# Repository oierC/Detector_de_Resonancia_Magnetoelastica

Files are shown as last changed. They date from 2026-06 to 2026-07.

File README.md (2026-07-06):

# Detector de Resonancia Magnetoelástica – Archivos del TFG

Este repositorio recopila los principales archivos desarrollados durante mi Trabajo Fin de Grado del Grado en Ingeniería Electrónica sobre el diseño y construcción de un dispositivo Detector de Resonancia Magnetoelástica.

<p align="center">
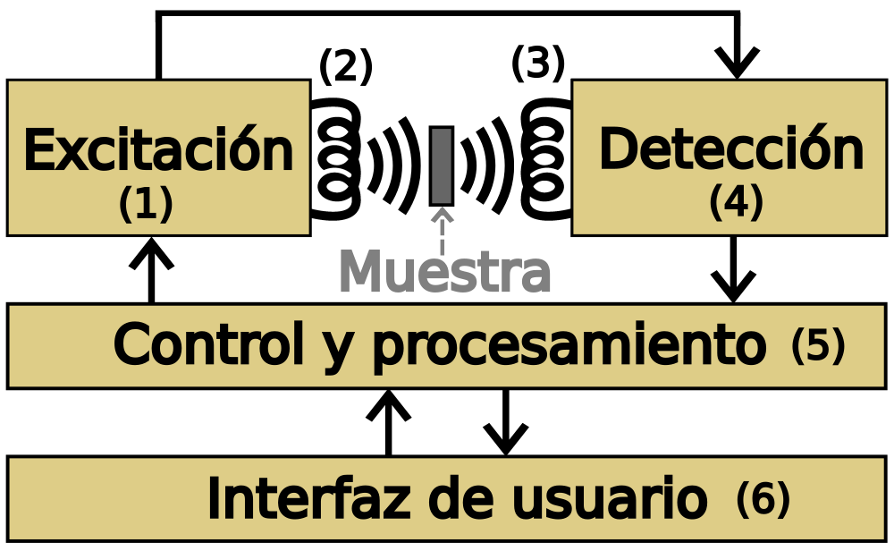
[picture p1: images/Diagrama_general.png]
  
</p>

El contenido se organiza en los siguientes tipos de archivos:

* **Arduino:** firmware principal del detector, desarrollado para ESP32. Se encarga del control de todos los elementos hardware del sistema, incluyendo el generador de señal, los convertidores DAC, el potenciómetro digital y la adquisición de datos mediante el ADC. Implementa distintos modos de funcionamiento (control manual, acceso a parámetros de calibración y barridos automáticos), gestionando la generación de campos magnéticos continuos y alternos, la ejecución de barridos en frecuencia y campo magnético, la adquisición de las señales de ganancia y fase, así como la comunicación con el software de control mediante el puerto serie. Además, incorpora comprobaciones de rango y resolución, junto con indicadores luminosos y acústicos para informar del estado del sistema y de posibles errores.

<p align="center">
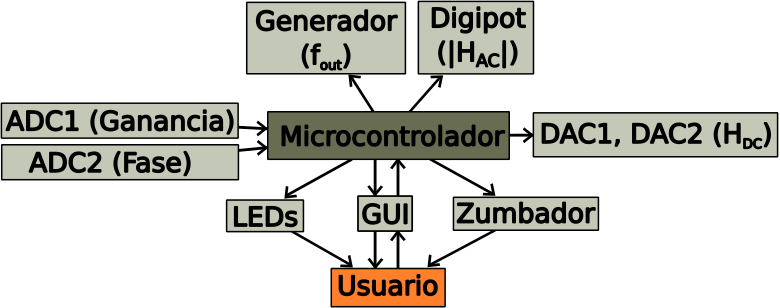
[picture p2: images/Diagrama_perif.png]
  
</p>

* **Python:** aplicación de escritorio desarrollada para el control del detector y la visualización de resultados. Proporciona una interfaz gráfica (GUI) desde la que es posible configurar los parámetros de medida, establecer barridos de frecuencia del campo magnético alterno y de valor del campo magnético estático, consultar los parámetros de calibración del sistema y comunicarse con el microcontrolador a través del puerto serie. Durante la adquisición de datos recibe en tiempo real las medidas de amplitud y fase, representa gráficamente su evolución, muestra la frecuencia de resonancia para cada valor de campo magnético estático y permite exportar los resultados obtenidos en formato CSV para su posterior análisis. Además, incorpora detección automática de dispositivos compatibles, gestión de errores y notificaciones del estado del sistema.

<p align="center">
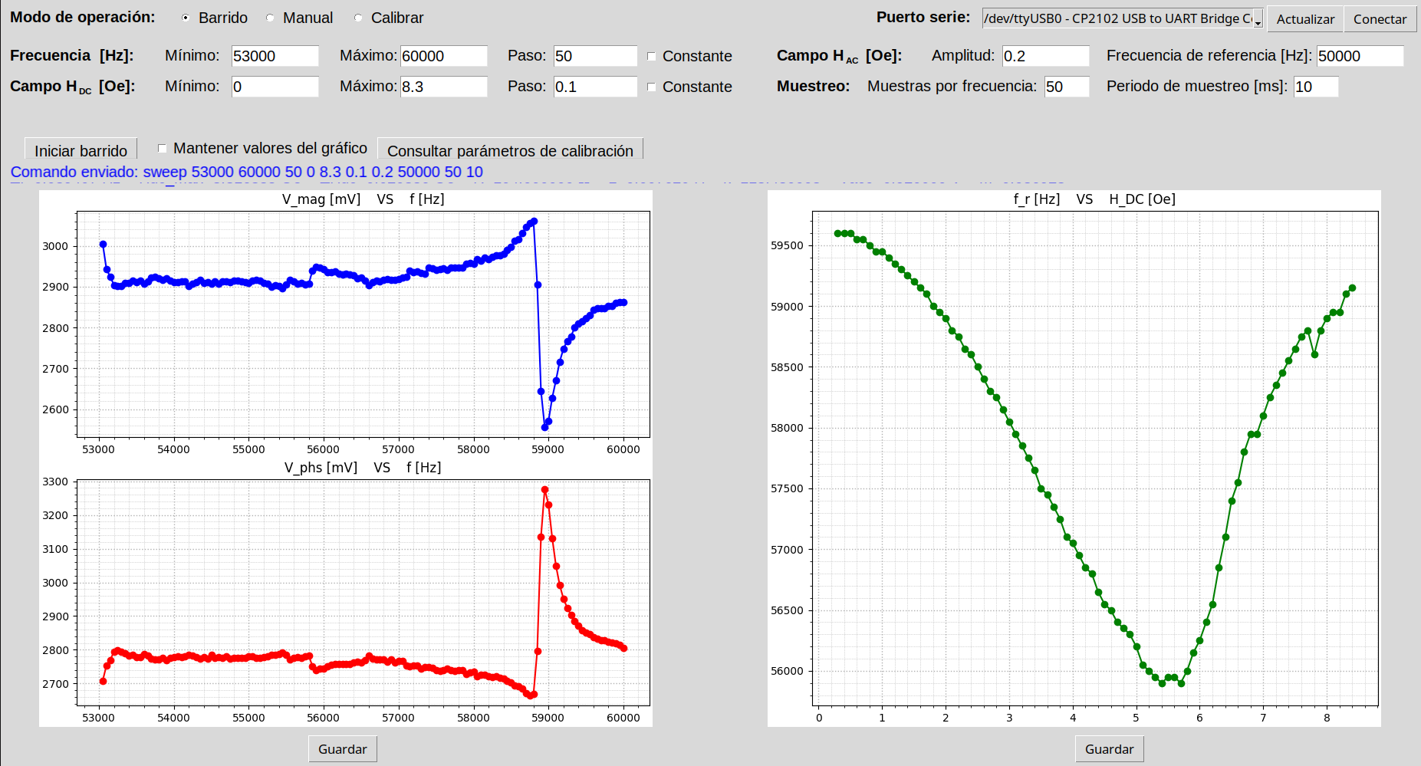
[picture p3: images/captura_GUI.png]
  
</p>

* **Modelos 3D:** diseños CAD de las piezas de PETG fabricadas para el sistema magnético encargado de generar y medir el campo magnético. Incluye dos soportes para fijar dos solenoides de forma coaxial. Estos soportes integran orificios para la introducción de muestras en el interior del sistema, cavidades para para el acoplamiento de conectores coaxiales y orificios roscantes que permiten fijar los solenoides mediante tornillos. Además, también incluye una tapa para cubrir la soldadura de los conectores y un portamuestras con referencias milimétricas que permiten posicionar las muestras en el interior del sistema.
  
<p align="center">
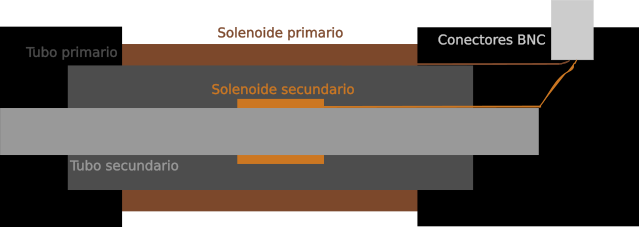
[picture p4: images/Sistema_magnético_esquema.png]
  
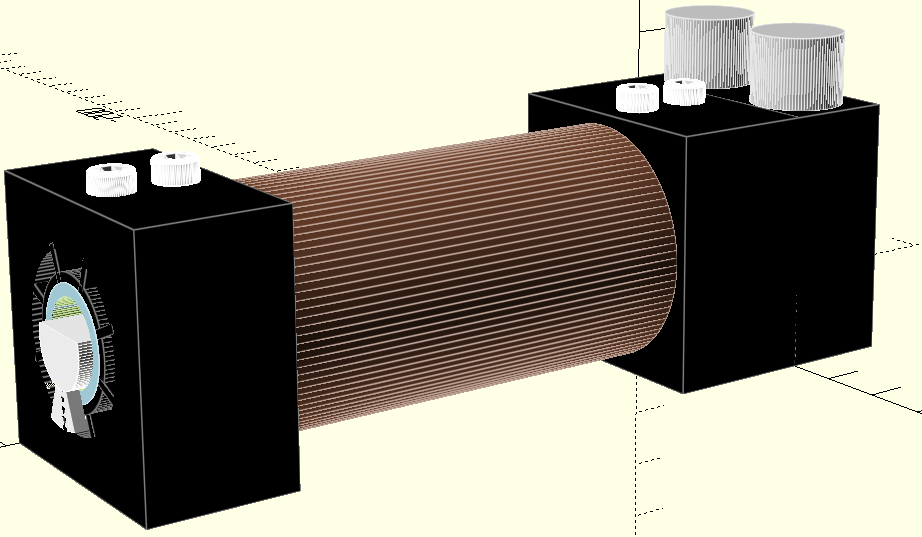
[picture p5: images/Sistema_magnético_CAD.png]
  
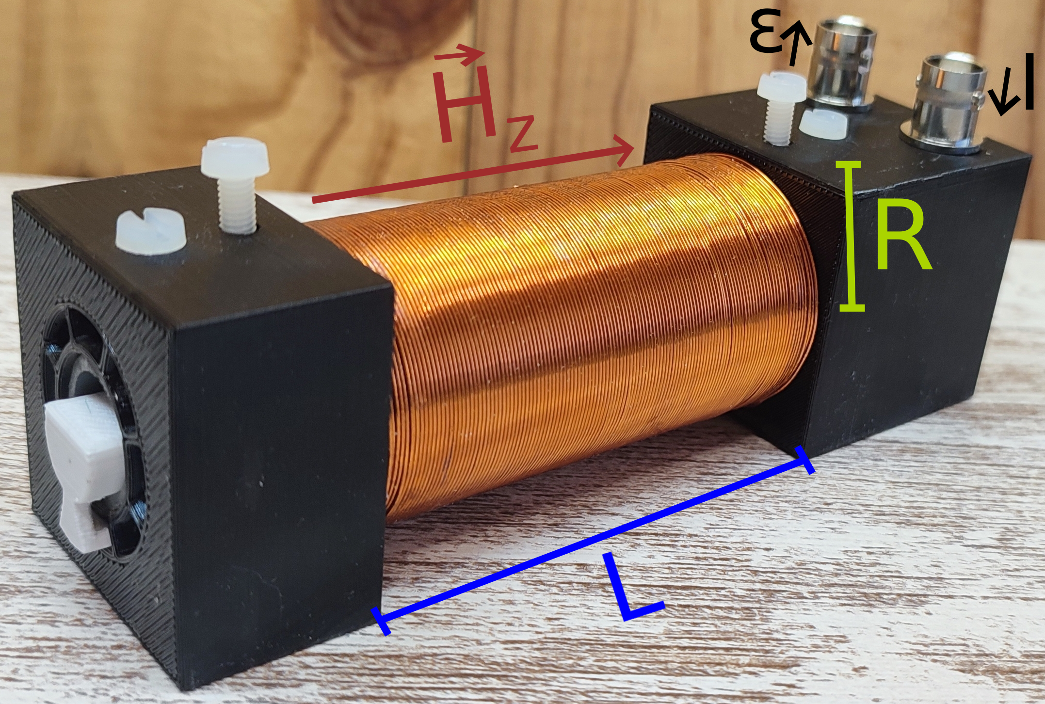
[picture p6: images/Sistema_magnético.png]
  
</p>
  
* **KiCad:** esquema eléctrico y diseño de la placa de circuito impreso (PCB) del prototipo preindustrializado desarrollado para el proyecto. Incluye el generador de señal, circuito de adecuación y amplificación, el detector de ganancia y fase, el sistema de control y procesamiento, un conector USB tipo-C para la comunicación y conectores coaxiales para el sistema magnético.
  
<p align="center">
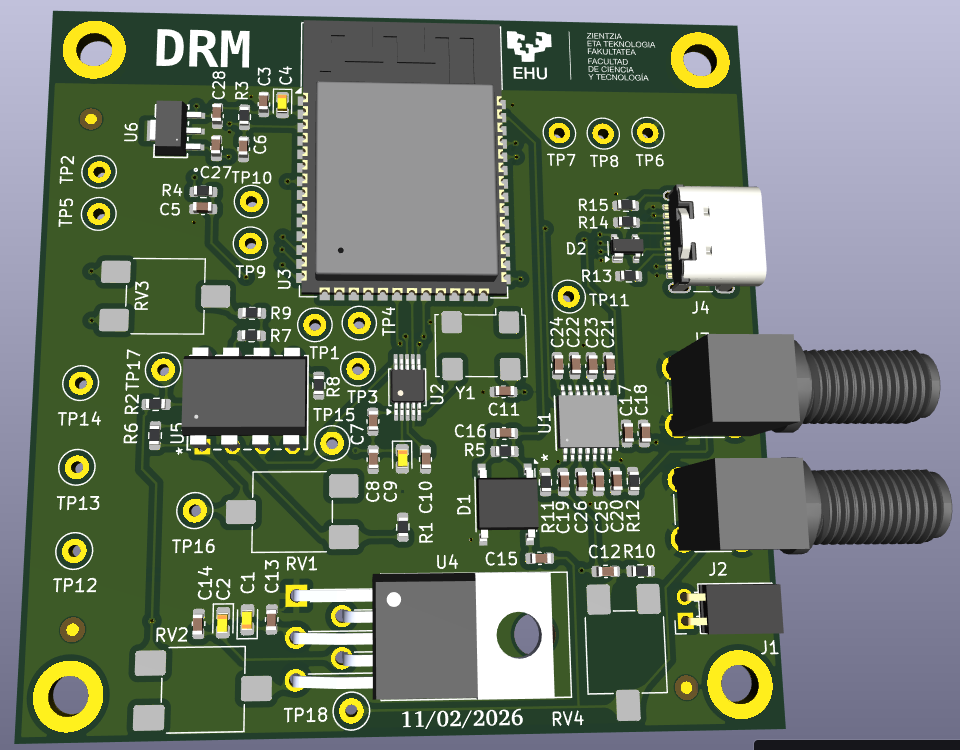
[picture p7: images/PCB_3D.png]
  

Este repositorio tiene como objetivo facilitar la consulta, reproducción y reutilización del trabajo realizado, reuniendo en un único lugar tanto el hardware como el software desarrollados para el proyecto.

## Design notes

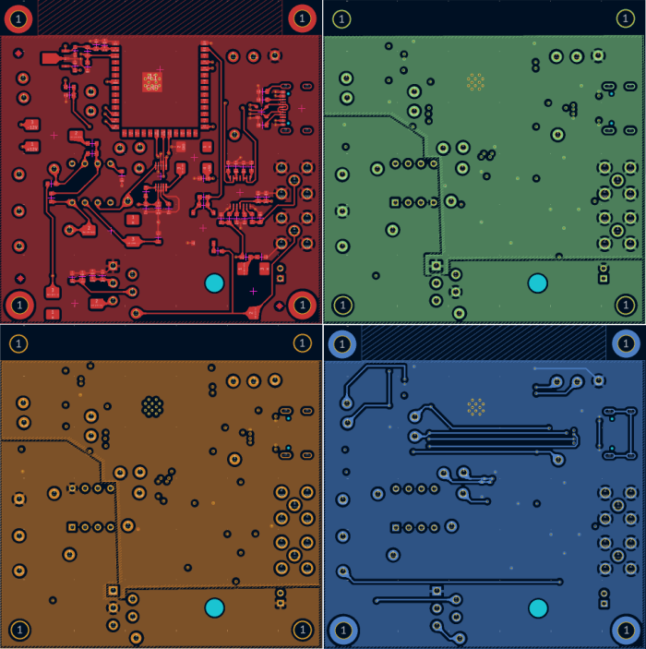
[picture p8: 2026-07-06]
images/PCB_capas.png

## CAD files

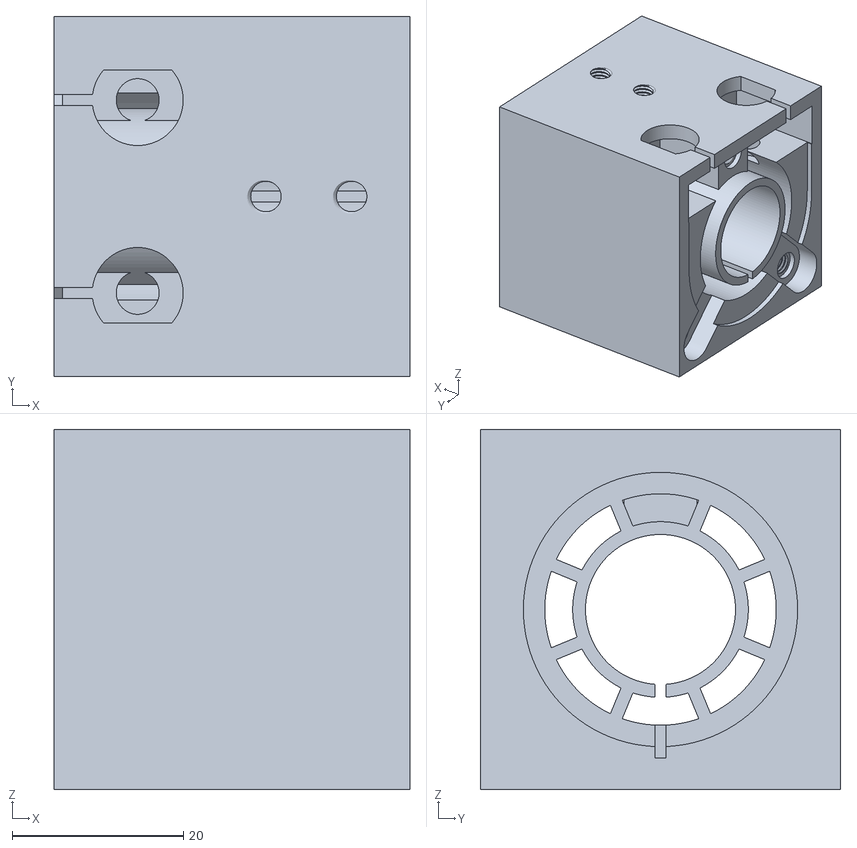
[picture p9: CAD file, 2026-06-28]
Modelos_3D/baseRight_V5.stl
41.5 x 42.0 x 42.0

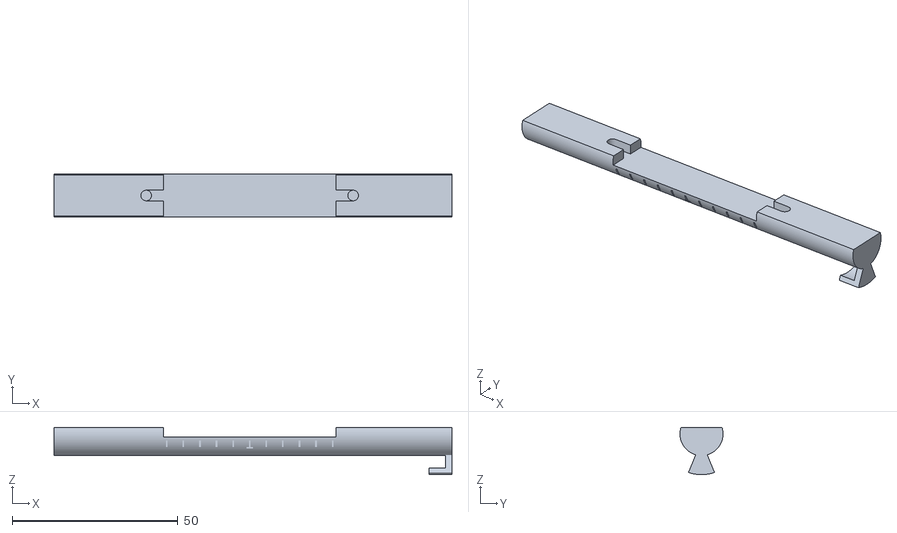
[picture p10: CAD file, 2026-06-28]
Modelos_3D/portamuestras_V7.stl
120.0 x 13.0 x 14.2

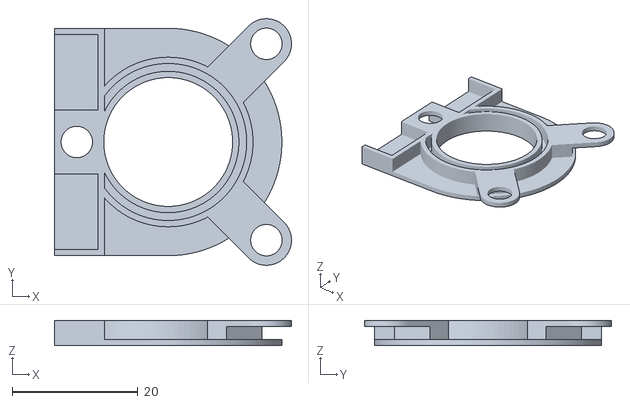
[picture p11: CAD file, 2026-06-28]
Modelos_3D/tapa_V5.stl
37.7 x 39.3 x 4.00

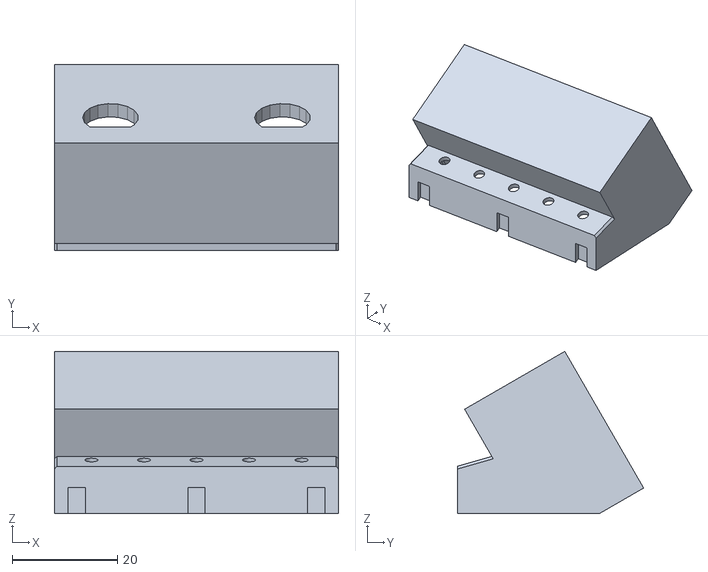
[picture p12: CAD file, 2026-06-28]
Modelos_3D/extension_SMA.stl
54.0 x 35.4 x 30.8

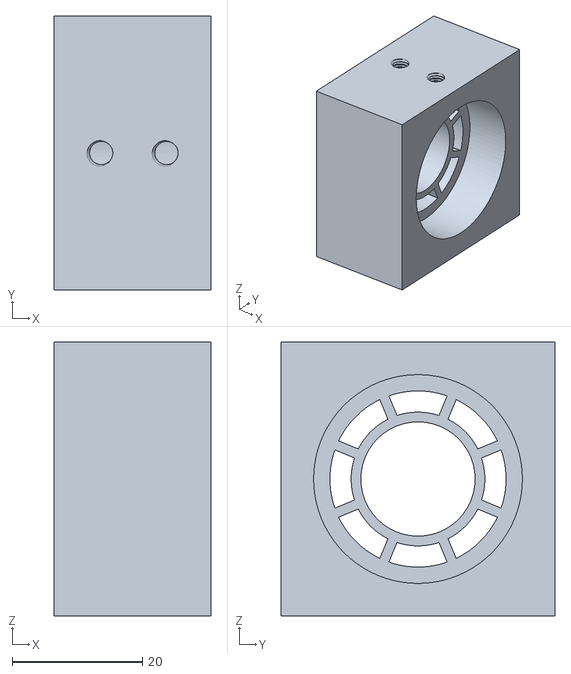
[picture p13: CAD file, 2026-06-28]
Modelos_3D/baseLeft_V5.stl
24.0 x 42.0 x 42.0

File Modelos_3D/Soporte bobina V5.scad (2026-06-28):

// Soporte bobina TFG Oier
//
dtp = 32; // diametro externo tubo primario
ltp = 90; // largo tubo primario
//ltp = 100; // largo tubo primario
dts = 17.5; // diametro externo tubo secundario;
gts = 2; // Grosor tubo secundario
thick = 24; // ancho de la pieza soporte
sobra = 5; // cuanto es mayor la pieza soporte del diametro del tubo
monta = 10; // longitud que monta en el soporte el tubo primario
anillo = 5; // anillo exterior de radios
lts = ltp+2*(thick-monta); // largo tubo secundario
sobra_sec = 3; // pared del soporte del secundario.
da =1.3; // diamtero agujero pasa hilos
desfase = 22.5;

//Parametros de tornillos:
dtorn = 5; //Diametro rosca tornillo. Nota: Este no es el diametro real de la rosca, es un agujero de un diametro más grande pensado para luego unirle por dentro un modelo 3D de tuerca de 4mm.
dcab = 8;  //Diametro cabeza tornillo. El diametro real es de 7, pero le damos un pequeño margen
lcab = 3; //Altura cabeza tornillo
ltorn1 = 5.3; //Largo tornillo1. Nota: Le hemos añadido un margen de 0.5mm.
ltorn2 = 12.7; //Largo tornillo2. Nota: Le hemos añadido un margen de 0.2mm.
ltuerca4mm = 3; //Altura de la tuerca de 4mm

//Parametros del conector SMA:
dr = 10.6; //diametro rosca del conector SMA
drmin = 8.8; //diametro de la zona con muesca muesca de la rosca del conector SMA
muesca= dr-drmin; //tamaño de la mordida
lr = 8; //largo rosca

dSMA = 15.5; //Diametro máximo del macho SMA
lSMA = 12; //Largo de la parte metálica del conector que queda en el exterior
dTuerca = 12.5;
lTuerca = 2.3;

dpunt = 5; //Diametro punta de cobre de SMA
lpunt = 7; //Largo punta de cobre de SMA

//Parametros de la extensión:
margenx = 10; //Margen de espacio entre el conector y la pared de la base
margeny = 2; //Margen de espacio entre el conector y los bordes de la extensión
margenz = 2; //Margen de altura entre el suelo y el SMA
//paredy = 2.9; //Grosor de las paredes en ele eje y
//paredx = 2.9; //Grosor de las paredes en ele eje x
pared = 2.9; //Grosor de las paredes. El fabricante del conector SMA indica explicitamente que la pared en la que se sujeta puede tener un groso máximo de 2.9mm
largo = margenx+lr; //Como de larga es la extensión
alto = dSMA+margenz; //Cómo de alta es la extensión

//Tapa cubre conexiones:
sobraTapa = 5; //Sobrante entre final de hueco y final de tapa
gruesoTapa = 1; //Grosor de la tapa
lDientes= lcab; //Como de largo serán los salientes que sujetan la tapa
dtapa = anillo+sobraTapa; //Diametro máximo de la parte cricular de la tapa
wBase=dtp+2*sobra-2*pared; //Anchura de la zona rectangular
hBase=dtp/2+sobra-pared; //Altura de la zona rectangular
dBase=wBase;    //dtp-anillo+sobraTapa; //Diametro de la zona circular.
lPalo=dBase+dcab;
wPalo=dcab;

//Portamuestras
lmmax = 50; //Longitud máxima de las muestras. Suelen ser de unos 30-50mm.
wmmax = 11; //Anchura máxima de las muestras. Suelen ser de unos 5mm.
hmmax = 1.65; //Altura máxima de las muestras. De momento no lo sé, supongamos 1mm.
lm = lmmax+2;
wm = wmmax+2;
hm = hmmax+0.2;
gsuelo = 2; //Grosor del suelo del portamuestras sobre el que se posaran las muestras.
hparedes=hm+2;
sport = 2; //Sobrante axial del portamuestras.
lsuj = 5;//Longitud del saliente de sujección
rsport = 2*gts+2*sobra_sec+1; //Sobrante radial del portamuestras.
gpatas = lsuj+5; //Grosor de las patas del portamuestras.
hpatas = dts/2-gts-gsuelo-hmmax/2; //altura de las patas.
//Largo tapaNeg = ltorn1+lcab+1 = 5.1 + 3 + 1= 10.1mm
//Largo extension = alto = dSMA+margenz = 15.5 + 2 = 17.7
$fn=100;

module m4nut(){
    import("/home/oier/Desktop/Code/3D/STL/working-m4-screws-and-nut-model_files/m4-nut.stl");
}

module tornillo_m4_5mm(){
    import("/home/oier/Desktop/Code/3D/STL/working-m4-screws-and-nut-model_files/m4-5mm-screw.stl");
}
module tornillo_m4_12mm(){
    import("/home/oier/Desktop/Code/3D/STL/working-m4-screws-and-nut-model_files/m4-12mm-screw.stl");
}


module soporte_primario() {
    translate([thick-monta, dtp/2+sobra, dtp/2+sobra]) rotate([0,90,0]) cylinder(h=ltp,d=dtp);
}

module soporte_secundario() {
    difference(){
        
        translate([0, dtp/2+sobra, dtp/2+sobra])
        rotate([0,90,0])
        cylinder(h=lts,d=dts);
        
        translate([-0.1, dtp/2+sobra, dtp/2+sobra])
        rotate([0,90,0])
        cylinder(h=lts+0.2,d=dts-2*gts);
    }
}

module radio(angle) {
    radio_thick = 1.5;
    translate([(thick-monta)/2,dtp/2+sobra, dtp/2+sobra]) 
    rotate([angle,0,0]) 
    cube([thick-monta,radio_thick,dtp-anillo+2], center = true);
}

module radioPorta(angle,radio_thick) {
    //radio_thick = 1.5;
    //translate([(thick-monta)/2,dtp/2+sobra, dtp/2+sobra]) 
    rotate([angle,0,0]) 
    cube([lsuj+sport+0.2,radio_thick,dtp-anillo+2], center = true);
}

module soporte() {
    
    difference() {
        union() {
            difference() {
              cube([thick,dtp+2*sobra,dtp+2*sobra]);
                soporte_primario();
                translate([0, dtp/2+sobra, dtp/2+sobra])
                rotate([0,90,0])
                cylinder(h=ltp,d=dtp-anillo, center=true);   
            }
            radio(0+desfase);
            radio(45+desfase);
            radio(90+desfase);
            radio(90+45+desfase);
            translate([0, dtp/2+sobra, dtp/2+sobra])
            rotate([0,90,0])
            cylinder(h=thick-monta,d=dts+sobra_sec);
        }
        translate([-1,0,0])
        soporte_secundario();
    }
}

module tornillo1(){
    translate([0,0,0])
    cylinder(h=ltorn1,d = dtorn);

    translate([0,0,ltorn1])
    cylinder(h=3,d = dcab);
}

module tornillo1V7mm(){
    translate([0,0,0])
    cylinder(h=ltorn1,d = dtorn);

    translate([0,0,ltorn1])
    cylinder(h=3,d = 7);
}

module tornillo2(){
    translate([0,0,0])
    cylinder(h=ltorn2,d = dtorn);

    translate([0,0,ltorn2])
    cylinder(h=3,d = dcab);
}

module pasacablesV1(){
    translate([-0.5*thick,dtp/2+sobra,sobra-0.25*da]) rotate([0,90,0]) cylinder(h=2*thick,d = da);
    translate([-0.5*thick,dtp/2+sobra,da]) rotate([0,90,0]) cylinder(h=2*thick,d = da);
    translate([-0.5*thick,dtp/2+sobra,dtp/2+sobra-dts/2]) rotate([0,90,0]) cylinder(h=2*thick,d = da);
    }
    
module pasacablesV2(){
    radio_thick = da;
    h= (dtp-dts)/2+da+1;
    h_pos=sobra-da;
    translate([-3,dtp/2+sobra-radio_thick/2,h_pos])
    cube([thick+6,radio_thick,h], center = false);
    }
    
module SMA(){
    union(){
        //Rosca:
        difference(){
            translate([0, 0, lpunt])
            rotate([0,0,0])
            cylinder(h=lr,d=dr);
            
            translate([-dr,dr/2-muesca,-1])
            cube([20,20,20], center = false);
        }
        //Exterior:
        translate([0,0,lr+lpunt])
        cylinder(h=lSMA,d=dSMA);
        
        //Tuerca:
        translate([0,0,lr+lpunt-pared-lTuerca])
        cylinder(h=lTuerca,d=dTuerca);
        
        //Punta:
        translate([0, 0, 0])
        rotate([0,0,0])
        cylinder(h=lpunt,d=dpunt);
        
    }
}

module SMA2(){
    //Este va ha ser para asegurar espacio de cavidad
    union(){
        //Rosca:
        difference(){
            translate([0, 0, lpunt])
            rotate([0,0,0])
            cylinder(h=lr,d=dr);
            
            translate([-dr,dr/2-muesca,-1])
            cube([20,20,20], center = false);
        }
        //Exterior:
        translate([0,0,lr+lpunt])
        cylinder(h=lSMA,d=dSMA);
        
        //Tuerca:
        translate([0,0,lr+lpunt-pared-lTuerca])
        cylinder(h=lTuerca,d=dTuerca);
        
        //Punta:
        translate([0, 0, 0])
        rotate([0,0,0])
        cylinder(h=lpunt,d=dpunt);
        
        //Cavidad:
        esp1_alto = 3*dr/4;
        esp1_ancho = dTuerca+1.5;
        translate([0,0,lpunt+lr-esp1_alto/2-pared])
        cube([esp1_ancho+10,esp1_ancho,esp1_alto], center=true);
        
    }
}

module dualSMA(){
//    margenx = 10; //Margen de espacio entre el conector y la pared de la base
//    margeny = 2; //Margen de espacio entre el conector y los bordes de la extensión
//    margenz = 2; //Margen de altura entre el suelo y el SMA
//    pared = 3; //Grosor de las paredes
    union(){
        rotate([180,90,0])
        translate([-(dSMA/2+margenz),-dSMA/2-margeny,margenx-lr])
        SMA();
        
        rotate([0,-90,0])
        translate([dSMA/2+margenz,dtp+2*sobra-dSMA/2-margeny,margenx-lr])
        SMA();
    }
}
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

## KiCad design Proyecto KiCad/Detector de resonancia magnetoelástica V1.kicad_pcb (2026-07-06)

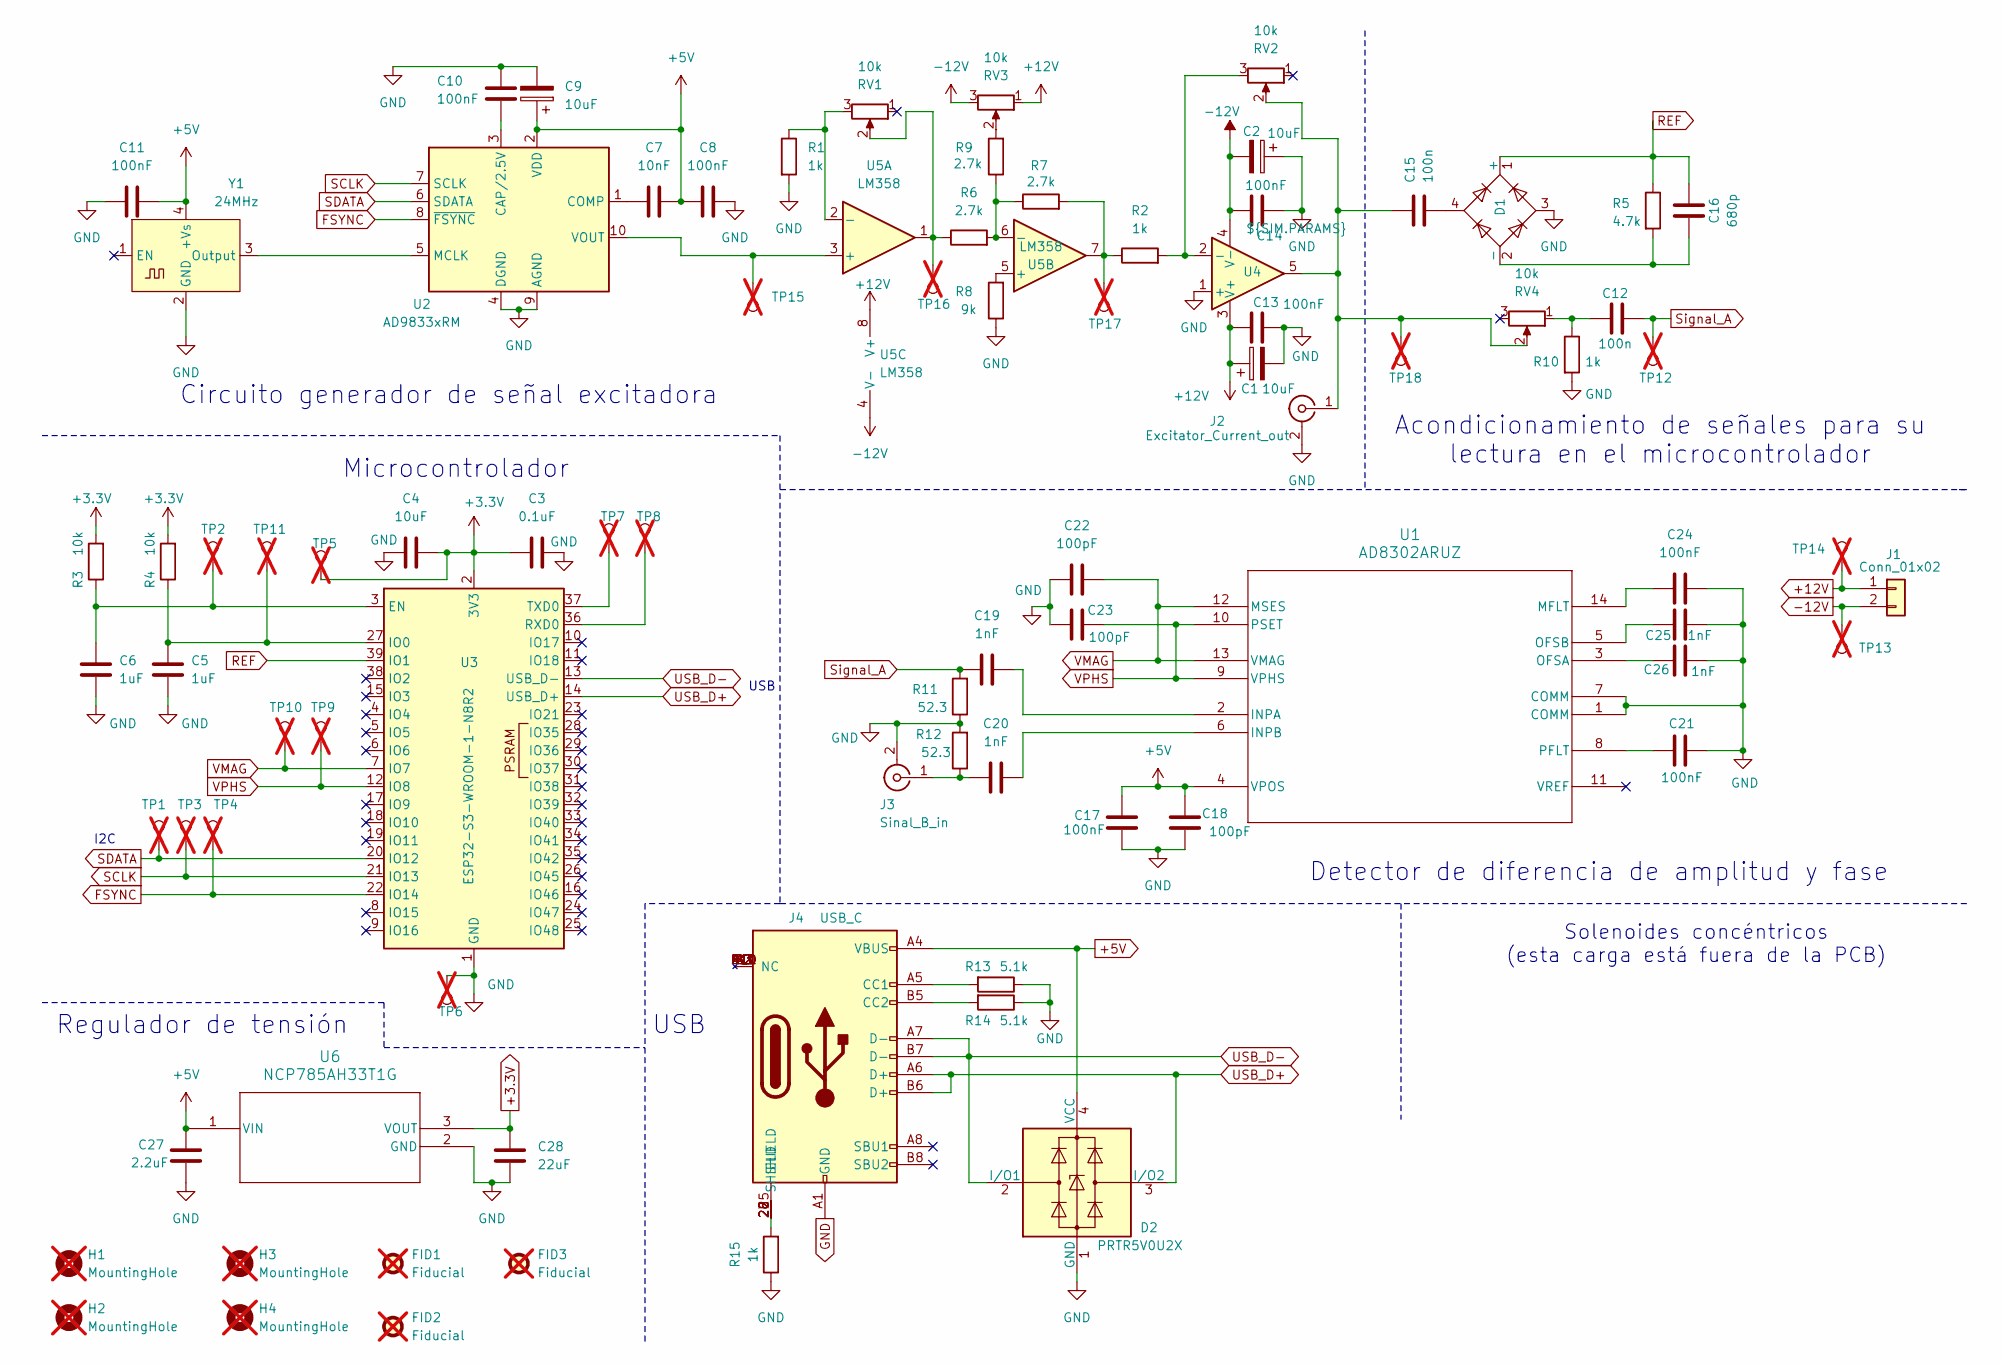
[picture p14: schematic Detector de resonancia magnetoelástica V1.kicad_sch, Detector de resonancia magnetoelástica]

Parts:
C1, C2, C4, C9: 10uF; CP_EIA-1608-08_AVX-J
C3: 0.1uF; C_0603_1608Metric
C5, C6: 1uF; C_0603_1608Metric
C7: 10nF; C_0603_1608Metric
C8, C10, C11, C13, C14, C17, C21, C24: 100nF; C_0603_1608Metric
C12, C15: 100n; C_0603_1608Metric
C16: 680p; C_0603_1608Metric
C18, C22, C23: 100pF; C_0603_1608Metric
C19, C20, C25, C26: 1nF; C_0603_1608Metric
C27: 2.2uF; C_0603_1608Metric
C28: 22uF; C_0603_1608Metric
D1: ABS2; Diode_Bridge_Diotec_ABS
D2: PRTR5V0U2X; SOT-143
FID1, FID2, FID3: Fiducial; Fiducial_1mm_Mask2mm; not fitted
H1, H2, H3, H4: MountingHole; MountingHole_3.2mm_M3_DIN965_Pad_TopBottom; not fitted
J1: Conn_01x02; PinSocket_1x02_P2.00mm_Horizontal
J2: Excitator_Current_out; SMA_Molex_73251-2200_Horizontal
J3: Sinal_B_in; SMA_Molex_73251-2200_Horizontal
J4: USB_C; USB_C_Receptacle_GCT_USB4105-xx-A_16P_TopMnt_Horizontal
R1, R2, R10, R15: 1k; R_0603_1608Metric
R3, R4: 10k; R_0603_1608Metric
R5: 4.7k; R_0603_1608Metric
R6, R7, R9: 2.7k; R_0603_1608Metric
R8: 9k; R_0603_1608Metric
R11, R12: 52.3; R_0603_1608Metric
R13, R14: 5.1k; R_0603_1608Metric
RV1, RV2, RV3, RV4: 10k; Potentiometer_ACP_CA6-VSMD_Vertical
TP1, TP2, TP3, TP4, TP5, TP6, TP7, TP8, TP9, TP10, TP11, TP12, TP13, TP14, TP15, TP16, TP17, TP18: TestPoint; TestPoint_Loop_D2.50mm_Drill1.0mm; not fitted
U1: AD8302ARUZ; RU_14_ADI-L
U2: AD9833xRM; MSOP-10_3x3mm_P0.5mm
U3: ESP32-S3-WROOM-1-N8R2; ESP32-S3-WROOM-1
U4: ${SIM.PARAMS}; TO-220-5_P3.4x3.8mm_StaggerOdd_Lead7.13mm_TabDown
U5: LM358; DIP8
U6: NCP785AH33T1G; SOT-89-3_2P7X4P7_ONS-M
Y1: 24MHz; Oscillator_SMD_IQD_IQXO70-4Pin_7.5x5.0mm

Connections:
+3.3V: C3.1, C4.2, C28.1, R3.2, R4.2, TP5.1, U3.2 (3V3), U6.3 (VOUT)
+5V: C7.2, C8.1, C9.1, C11.2, C17.1, C18.1, C27.1, D2.4 (VCC), J4.A4 (VBUS), J4.A9 (VBUS), J4.B4 (VBUS), J4.B9 (VBUS), U1.4 (VPOS), U2.2 (VDD), U6.1 (VIN), Y1.4 (+Vs)
+12V: C1.1, C13.2, J1.1, RV3.1, TP14.1, U4.3 (V+), U5.8 (V+)
-12V: C2.2, C14.2, J1.2, RV3.3, TP13.1, U4.4 (V-), U5.4 (V-)
FSYNC: TP4.1, U2.8 (~FSYNC), U3.22 (IO14)
GND: C1.2, C2.1, C3.2, C4.1, C5.2, C6.2, C8.2, C9.2, C10.2, C11.1, C13.1, C14.1, C17.2, C18.2, C21.2, C22.1, C23.1, C24.2, C25.2, C26.2, C27.2, C28.2, D1.3, D2.1 (GND), J2.2 (Ext), J3.2 (Ext), J4.A1 (GND), J4.A12 (GND), J4.B1 (GND), J4.B12 (GND), R1.2, R8.1, R10.2, R11.1, R12.2, R13.1, R14.1, R15.1, TP6.1, U1.1 (COMM), U1.7 (COMM), U2.4 (DGND), U2.9 (AGND), U3.1 (GND), U3.40 (GND), U3.41 (GND), U4.1 (+), U6.2 (GND), Y1.2 (GND)
unnamed: C12.1, R10.1, RV4.1
unnamed: C15.2, D1.4
unnamed: C16.1, D1.2 (-), R5.2
unnamed: C15.1, J2.1 (In), RV2.2, RV4.2, TP18.1, U4.5
unnamed: C20.1, J3.1 (In), R12.1
unnamed: J4.A5 (CC1), R13.2
unnamed: J4.B5 (CC2), R14.2
unnamed: J4.25 (SHIELD), J4.26 (SHIELD), J4.27 (SHIELD), J4.28 (SHIELD), J4.S1, R15.2
unnamed: R2.1, R7.2, TP17.1, U5.7
unnamed: R6.1, RV1.2, TP16.1, U5.1
unnamed: R9.2, RV3.2
unnamed: C19.2, U1.2 (INPA)
unnamed: C20.2, U1.6 (INPB)
unnamed: C24.1, U1.14 (MFLT)
unnamed: C26.1, U1.3 (OFSA)
unnamed: C25.1, U1.5 (OFSB)
unnamed: C21.1, U1.8 (PFLT)
unnamed: C10.1, U2.3 (CAP/2.5V)
unnamed: C7.1, U2.1 (COMP)
unnamed: U2.5 (MCLK), Y1.3 (Output)
unnamed: TP15.1, U2.10 (VOUT), U5.3 (+)
unnamed: C6.1, R3.1, TP2.1, U3.3 (EN)
unnamed: C5.1, R4.1, TP11.1, U3.27 (IO0)
unnamed: TP8.1, U3.36 (RXD0)
unnamed: TP7.1, U3.37 (TXD0)
unnamed: R2.2, RV2.3, U4.2 (-)
unnamed: R1.1, RV1.3, U5.2 (-)
unnamed: R8.2, U5.5 (+)
unnamed: R6.2, R7.1, R9.1, U5.6 (-)
REF: C16.2, D1.1 (+), R5.1, U3.39 (IO1)
SCLK: TP3.1, U2.7 (SCLK), U3.21 (IO13)
SDATA: TP1.1, U2.6 (SDATA), U3.20 (IO12)
Signal_A: C12.2, C19.1, R11.2, TP12.1
USB_D+: D2.3 (I/O2), J4.A6 (D+), J4.B6 (D+), U3.14 (USB_D+)
USB_D-: D2.2 (I/O1), J4.A7 (D-), J4.B7 (D-), U3.13 (USB_D-)
VMAG: C22.2, TP10.1, U1.12 (MSES), U1.13 (VMAG), U3.7 (IO7)
VPHS: C23.2, TP9.1, U1.9 (VPHS), U1.10 (PSET), U3.12 (IO8)

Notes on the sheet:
Detector de diferencia de amplitud y fase
Circuito generador de señal excitadora
USB
Regulador de tensión
Microcontrolador
I2C
Solenoides concéntricos (esta carga está fuera de la PCB)
USB
Acondicionamiento de señales para su lectura en el microcontrolador

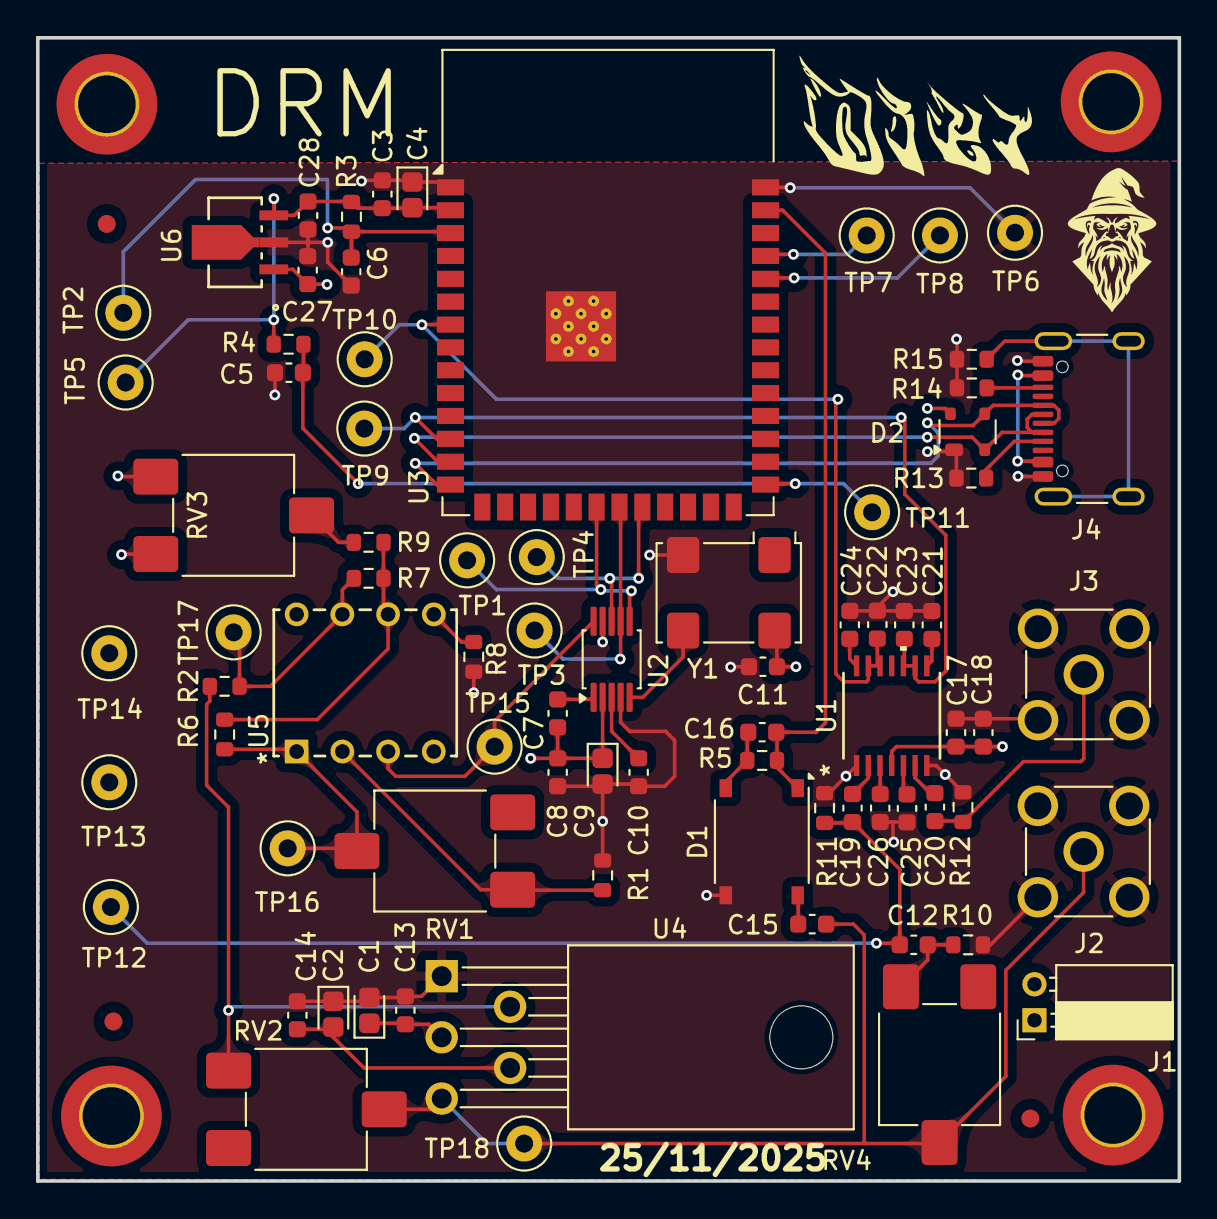
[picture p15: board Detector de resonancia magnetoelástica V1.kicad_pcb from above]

Board: 4 copper layers, 63.4 x 63.5 mm, 85 parts (0 on the bottom side), 43 nets.

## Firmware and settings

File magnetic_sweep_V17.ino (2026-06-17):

/// Título: magnetic_sweep_V10
/// Descripción:
/// * V7: Controla el generador de señales sinusoidales a través del puerto serie con dos sencillas funciones con instrucciones en binario.
/// * V8: Se implementa el multitasking para controlar los indicadores LED.
/// * V8: Se implementa la interfaz de indicadores LED y zumbador.
/// * V9: Se implementa el control de los DAC.
/// * V10: Ligera mejora del control del DAC y el generador para poder hacer barridos manteniendo frecuencia o Hdc constantes.
/// * V11: Se implementa el control del digipot.
/// * V11: Se implementa recogida de errores de resolución y rango de frecuencia, campo H continuo y campo H alterno.
/// * V12: Se implementa recolección de datos a través del ADC.
/// * V13: Se implementan melodías en lugar de pitidos.
/// * V14: Se han ajustado los periodos de cambio de frecuencia y muestreo.
/// * V14: Se ha hecho un ajuste en los bucles de f y Hdc, ya que no llegaban nunca a tomar medidas con los valores máximos.
/// * V15: Se implementa la recogida de más errores de resolución y rango de frecuencia y campo H continuo.
/// * V15: Las variables samples_per_f y sample_period son ahora parámetros de entrada.
/// * V16: El primer parámetro de entrada pasa a ser una cadena de caracteres que indica el comando. Entradas admitidas, cmd="sweep","params"
/// * V17: Añadido los comandos cmd="man" para control manual y cmd="raw" para control a través de los valores en crudo de registros.

// Los comandos de entrada del microcontrolador tendrán siempre los mismos 8 parámetros separados por espacios:
// char[10] cmd    float f_min    float f_max    float f_step    float Hdc_min    float Hdc_max    float Hdc_step    H0_1Hz
// Si cmd="sweep" --> se pone en marcha el sistema magnético con los parámetros indicados; Si cmd = "params" --> El microcontrolador devuelve los parámetros de calibración guardados en su memoria.


// Ejemplo de comando:
// 0 50000 65000 1000 0 2 1 0.15 50000

#include <SPI.h>

// Parámetros de calibración
// >>Nota: El usuario debe ajustar estos valores en función de los componentes empleados y la calibración realizada mediante potenciómetros.
const float f_MCLK = 24*pow(10,6); // Hz // Introducir frecuencia del oscilador externo del generador de señal AD9833.
const float R = 104; // Ohms // Introducir valor de resistencia de carga.
const float L = 0.00762; // Henrios // Introducir valor de inductancia del solenoide primario.
const float k = 118.48; // 1/m // Introducir constante de solenoide del solenoide primario.
const float Voffset = -0.046;//345; // Volts // Introducir tensión medida con el generador en modo reposo y los DACs apagados.
//const float Vdc1_max = 1.945; // Volts // Introducir tensión máxima medida con DAC1 (DAC2=0).
//const uint8_t DAC2_min = 255; // Introducir valor del DAC1 en escala de 8 bits al medir la tensión máxima.
const float Vdc2_min = -7.3; // Volts // Introducir tensión mínima medida con DAC2 (DAC1=0).
const uint8_t DAC2_min = 255; // Introducir valor del DAC2 en escala de 8 bits al medir la tensión mínima.
const float Vdc1_max = 0.055; // Volts // Introducir con que aporte míninimo de tensión de DAC1 se iguala o supera al Voffset o -kv2. Es decir, Vdc1 mínimo para que: Vdc1>=Voffset o Vdc1>=(-kv2). Este será el aporte máximo de Vdc1 que empleará este programa.
const uint8_t DAC1_max = 3; // Introducir valor del DAC1 en escala de 8 bits al medir la tensión anterior. Este será el valor de DAC máximo que empleará este programa.
const float Vac0 = 0.92; // Volts // Introducir amplitud de tensión medida en la salida cuando digipot=0;
const float Vac_max = 7.4; // Volts // Introducir amplitud de tensión máxima medida en la salida.
const uint8_t digipot_max = 180; // Introducir valor de entrada del digipot en escala de 8 bits al medir la tensión anterior.
const float Vac_punto = 2.6; // Volts // Introducir amplitud de tensión medida en la salida para un valor intermedio del digipot.
const uint8_t digipot_punto = 50; // Introducir valor de entrada del digipot en escala de 8 bits al medir la tensión anterior.

// Parámetros derivados de los parámetros de calibración introducidos.
// >> Nota: Los cálculos y funciones se han hecho suponiendo que DAC2 es coarse tuning (ya que depende únicamente de una de las resistencias variables) y que DAC1 es para fine tuning, por lo que Hdc estará en el rango negativo. A partir de ahora cada vez que se mencione Hdc se estará refiriendo a su módulo.
const float clock_constant = pow(2,28) / f_MCLK; // s // Constante de proporcionalidad que determina el valor requerido en el registro de frecuencia para lograr una determinada frecuencia de salida.
const float f_step_min = 1/clock_constant; // Hz // Resolución de frecuencia del generador de señal.
const float kv2 = (Vdc2_min+Voffset)/DAC2_min; // Volts // Salida de tensión continua dependiente de la salida del DAC2: Vdc2 = kv2*V_DAC2;
const float kv1 = Vdc1_max/DAC1_max; // Volts // Salida de tensión continua dependiente de la salida del DAC1: Vdc1 = kv1*V_DAC1;
// Hdc = k*(Vdc1+Vdc2)/R
const float Hdc_absolute_max = -k*Vdc2_min/R; // Oersteds // Valor máximo del campo magnético continuo que puede proporcionar el sistema.
const float Hdc_step_min = k*kv1/R; // Oersteds // Resolución del campo magnético.
const float m = (Vac_max-Vac_punto)/(digipot_max-50); // Pendiente de la ganancia de la amplitud en función del valor del digipot
// Hac = k*Gm*(Vac0+m*digipot_valor), donde Gm es la transconductancia de la carga de salida y digipot_valor es el valor de entrada del digipot en escala de 8 bits.


// SPI conexiones
#define csPin_wavegen 5   // AD9833 CS -> ESP32 GPIO5
#define csPin_digipot 15   // MCP4151 CS -> ESP32 GPIO5
#define sckPin 18  // SPI SCK -> ESP32 GPIO18
#define mosiPin 23  // SPI MOSI -> ESP32 GPIO23

// Indicadores LED
#define ledPin_V 21 // Verde
#define ledPin_A 19 // Azul
#define ledPin_R 17 // Rojo

// Zumbador
#define buzzerPin 16

// DACs
#define dacPin 25   //DAC1
#define dacPin2 26   //DAC2

// ADCs
#define gainPin 4 // Salida detector de ganancia
#define phasePin 2 // Salida detector de fase

// Configuraciones de SPI
SPISettings wavegenSettings(1000000, SPI_MSBFIRST, SPI_MODE2); //En el AD9833 es SPI_MSBFIRST.
SPISettings digipotSettings(1000000, SPI_MSBFIRST, SPI_MODE0);

// Variables globales
int modo = 0; // Modo = 0 --> Conexión por puerto serie (LED verde); Modo = 1 --> Conexión por WiFi (LED rojo); Modo = 2 --> Conexión por Bluetooth (LED azul)
// bool request = true; // request = true --> En reposo (solo se enciende en LED del modo correspondiente); request = false --> Campo magnético activo (barrido de los 3 LEDs en bucle). Al recibir por el puerto serie request=true, envía los parámetros de calibración.
float last_f = 0; // Hz // Para tener constancia a nivel global del valor actual de f y evitar redundancias.
float last_Hdc = 0; // Oersted // Para tener constancia a nivel global del valor actual de Hdc y optimizar procesos.
float last_Hac = 0; // Oersted // Para tener constancia a nivel global del valor actual de Hac y optimizar procesos.
float f_min = 0; // Hz
float f_max = 100000; // Hz
float f_step = 50; // Hz //Originalmente era 50
uint8_t DAC1_valor = 0; // Valor del registro del DAC1
uint8_t DAC2_valor = 0; // Valor del registro del DAC2
uint8_t digipot_valor = 0; // Valor del registro del digipot
float Hdc_min = 0; // Oersted
float Hdc_max = 0; // Oersted
float Hdc_step = 0; // Oersted
float Hac_at_f = 0; // Oersted // Valor del campo deseado a f_at_Hac Hz.
float f_at_Hac = 0; // Hz // Frecuencia a la que se desea la amplitud de campo Hac_at_f.
bool barrido = false; // Indica que hay un barrido en proceso
int samples_per_f = 30; // Cantidad de muestras por cada valor de frecuencia. // Valor recomedado para máxima velocidad: 30. Valor recomendado para mayor equilibrio velocidad/precisión: 50.
int sample_period = 10; // ns
char cmd[10];

// Melodias
struct Note {
    int freq;
    int duration;
};

#define C3  131
#define CS3 139
#define E3  165
#define F3  175
#define FS3 185
#define G3  196
#define GS3 208
#define A3  220
#define AS3 233
#define C4  262
#define CS4 277

Note deviceInitialization[] = {
    {C3, 120},
    {C4, 120},
    {G3, 120},
    {E3, 120},
    {C4, 100},
    {G3, 140},
    {E3, 240},

    {E3, 60},
    {F3, 60},
    {FS3, 60},
    {FS3, 60},
    {G3, 60},
    {GS3, 60},
    {GS3, 60},
    {A3, 60},
    {AS3, 60},
    {C4, 180},
};

Note connected[] = {
    {523, 80},
    {659, 80},
    {784, 80},
    {1047, 150}
};

Note commandError[] = {
    {440, 200},
    {330, 300}
};

Note sweepStart[] = {
    {1200, 40},
    {1350, 40},
    {1500, 40},
    {1800, 80},
    {1600, 50}
};

Note sweepEnd[] = {
    {900, 120},
    {1100, 120},
    {900, 120},
    {1100, 200}
};

// Se define una tarea que será ejecutada en un núcleo diferente al del programa principal, con el fin de ejecutar la animación de luces LED en paralelo al programa principal.
TaskHandle_t Task1;

void initializeWavegen(){
  SPI.beginTransaction(wavegenSettings);
  digitalWrite(csPin_wavegen, LOW);
  SPI.transfer16(0b0010000100000000);//(0b0010000100000000); ///Preparar reg. control, RESET, B28
  SPI.transfer16(0b0100000000000000); // FREQREG LSB
  SPI.transfer16(0b0100000000000000); // FREQREG MSB
  SPI.transfer16(0b1100000000000000); // Reg. fase=0
  SPI.transfer16(0b0010000001000000);//(0b0010000000000000); // Cargar reg. interno, modo reposo
  digitalWrite(csPin_wavegen, HIGH);
  SPI.endTransaction();
  last_f = 0;
}

void setWavegenFrecuency(float f_out){
  if (f_out < 0) f_out = -f_out; // Para corregir la entrada de posibles frecuencias negativas.
  if (f_out != last_f){
    uint32_t FREQREG = f_out * clock_constant; // Valor que debe tener FREQREG para conseguir una salida de frecuencia f_out.
    uint16_t LSB = 0b0100000000000000 | (0b0011111111111111 & FREQREG); //0b00001110100000;
    uint16_t MSB = 0b0100000000000000 | (0b0011111111111111 & (FREQREG>>14)); //0b00000000011011;
    SPI.beginTransaction(wavegenSettings);
    digitalWrite(csPin_wavegen, LOW);
    SPI.transfer16(0b0010000000000000); //Preparar reg. control, RESET, B28, forma de onda sinusoidal
    SPI.transfer16(LSB); // FREQREG LSB
    SPI.transfer16(MSB); // FREQREG MSB
    SPI.transfer16(0b0010000000000000); // Cargar reg. interno, activar salida
    digitalWrite(csPin_wavegen, HIGH);
    SPI.endTransaction();
    last_f = f_out;
  }
}

void setDigipot(uint8_t valor) {
  SPI.beginTransaction(digipotSettings);
  digitalWrite(csPin_digipot, LOW);
  SPI.transfer(0x00); // Dirección del registro del wiper
  SPI.transfer(valor); // Valor del wiper en escala de 0-255
  digitalWrite(csPin_digipot, HIGH);
  SPI.endTransaction();
}

void setDACsFromHdc(float Hdc){
  if (Hdc != last_Hdc){
    float Vdc = -(Hdc*R/k)-Voffset;
    if (Vdc<0){
      DAC2_valor = (int)(Vdc/kv2)+1;
      DAC1_valor = (int)(-(DAC2_valor*kv2-Vdc)/kv1);
    }
    else if (Vdc>0){
      DAC2_valor = 0;
      DAC1_valor = (int)(Vdc/kv1);
    }
    else{
      DAC2_valor = 0;
      DAC1_valor = 0;
    }
    dacWrite(dacPin, DAC1_valor);
    dacWrite(dacPin2, DAC2_valor);
    last_Hdc = Hdc;
    // float Vdc2 = DAC2_valor*kv2;
    // float Vdc1 = DAC1_valor*kv1;
    // float Hdc_conseguido = -(Vdc1+Vdc2)*k/R;
    // Serial.printf("Vdc=%f  DAC2_valor=%d  DAC1_valor=%d  Vdc2=%f Vdc1=%f Hdc_conseguido=%f\n",Vdc,DAC2_valor,DAC1_valor,Vdc2,Vdc1,Hdc_conseguido);
  }
}

bool setDigipotFromHac(float Hac, float f){
  if (Hac != last_Hac){
    float Gm = 1/sqrt(pow(R,2)+pow(2*PI*f*L,2));
    float digipot_valor_float = (Hac/(k*Gm)-Vac0)/m;
    digipot_valor = (int)digipot_valor_float;
    if (digipot_valor_float>=0 && digipot_valor_float<256){
      setDigipot(digipot_valor);
      last_Hac = Hac;
      //Serial.printf("Hac=%f f=%f Gm=%f digipot_valor=%d\n",Hac,f,Gm,digipot_valor);
      return true;
    }
    else {Serial.printf("ERROR: Campo H alterno fuera de rango. Rango de valores permitido para %f Hz: |Hac|∈(%f,%f)\n",f,k*Gm*Vac0,k*Gm*Vac_max);playMelody(commandError,sizeof(commandError));return false;}
  }
}

void playMelody(Note *melody, int totalSize) {
    for (int i = 0; i < totalSize/8; i++) {
        tone(buzzerPin, melody[i].freq, melody[i].duration);
        delay(melody[i].duration * 1.3);
    }
}



void setup() {
  Serial.begin(115200);
  delay(10);
  //Dejamos desactivado el canal del digipot:
  pinMode(csPin_digipot, OUTPUT);
  digitalWrite(csPin_digipot, HIGH);
  delay(10); // Quitar si no hace falta.
  //Inicializamos el generador con CS desactivado:
  pinMode(csPin_wavegen, OUTPUT);
  digitalWrite(csPin_wavegen, HIGH);
  delay(10); // Quitar si no hace falta.
  pinMode(ledPin_V, OUTPUT);
  pinMode(ledPin_A, OUTPUT);
  pinMode(ledPin_R, OUTPUT);
  pinMode(buzzerPin, OUTPUT);
  setDACsFromHdc(0);
  setDigipot(0);
  SPI.begin(sckPin, -1, mosiPin, -1);
  delay(10); // Quitar si no hace falta.
  initializeWavegen();
  delay(10);
  analogSetAttenuation((adc_attenuation_t)2); // Limita el rango de entrada del ADC a 2V.
  //create a task that will be executed in the Task1code() function, with priority 1 and executed on core 0
  xTaskCreatePinnedToCore(
                    Task1code,   /* Task function. */
                    "Task1",     /* name of task. */
                    10000,       /* Stack size of task */
                    NULL,        /* parameter of the task */
                    1,           /* priority of the task */
                    &Task1,      /* Task handle to keep track of created task */
                    0);          /* pin task to core 0 */                   
  delay(2000);
  Serial.println("¡Bienvenido a la interfaz de control del detector de resonancia magnetoelástica!"); // Esto permite comprobar de forma visual que la conexión serial se ha efectuado correctamente.
  Serial.println("La estructura de la introducción comandos es la siguiente:");
  Serial.println("cmd f_min f_max f_step Hdc_min Hdc_max Hdc_step Hac_at_f f_at_Hac samples_per_f sample_period");
  playMelody(deviceInitialization,sizeof(deviceInitialization));
}

// Función que controla los indicadores LED. Se ejecuta en el core 0 en paralelo al void loop, el cual se ejecuta en el core 1.
void Task1code( void * pvParameters ){
  bool lastModo = 3; // El modo=3 es un pseudo-modo para indicar que ha habido un barrido o que se están inicializando los LEDs.
  for(;;){ // Bucle for infinito
    delay(10);
    if ((modo==0) && (lastModo!=0)){
      digitalWrite(ledPin_V, HIGH);
      digitalWrite(ledPin_R, LOW);
      digitalWrite(ledPin_A, LOW);
      lastModo = modo;
    }
    else if ((modo==1) && (lastModo!=1)){
      digitalWrite(ledPin_V, LOW);
      digitalWrite(ledPin_R, HIGH);
      digitalWrite(ledPin_A, LOW);
      lastModo = modo;
    }
    else if ((modo==2) && (lastModo!=2)){
      digitalWrite(ledPin_V, LOW);
      digitalWrite(ledPin_R, LOW);
      digitalWrite(ledPin_A, HIGH);
      lastModo = modo;
    }
    else if (barrido){
      playMelody(sweepStart,sizeof(sweepStart));
      while (barrido){
        digitalWrite(ledPin_V, HIGH);
        delay(666);
        digitalWrite(ledPin_V, LOW);
        digitalWrite(ledPin_R, HIGH);
        delay(666);
        digitalWrite(ledPin_R, LOW);
        digitalWrite(ledPin_A, HIGH);
        delay(666);
        digitalWrite(ledPin_A, LOW);
      }
      playMelody(sweepEnd,sizeof(sweepEnd));
      lastModo = 3;
    }
  } 
}

void loop() {
  delay(100);
  if (Serial.available()) {
    String line = Serial.readStringUntil('\n');
    //Serial.println(line);
    line.trim();
    // int request_int;
    sscanf(line.c_str(), "%9s %f %f %f %f %f %f %f %f %d %d", &cmd, &f_min, &f_max, &f_step, &Hdc_min, &Hdc_max, &Hdc_step, &Hac_at_f, &f_at_Hac, &samples_per_f, &sample_period);
    //request = (request_int != 0);

    //Serial.printf("request=%d  f_min=%.1f  f_max=%.1f  f_step=%.1f Hdc_min=%.2f Hdc_max=%.2f Hdc_step=%.2f\n",request,f_min,f_max,f_step,Hdc_min,Hdc_max,Hdc_step);


    if (strcmp(cmd, "params") == 0){
      Serial.printf("CALIB:    Δf=%f Hz    Hdc_max=%f Oe    ΔHdc=%f Oe    R=%f Ω    L=%f H    k=%f    Vac0=%f V    m=%f\n",f_step_min,Hdc_absolute_max,Hdc_step_min,R,L,k,Vac0,m); // Devuelve los parámetros de calibración y derivados.
    }

    // else if (strcmp(cmd, "stop") == 0){
    //   barrido = false;
    // }

    else if (strcmp(cmd, "raw") == 0){
      setWavegenFrecuency(f_min);
      DAC1_valor = (int) f_max;
      DAC2_valor = (int) f_step;
      dacWrite(dacPin, DAC1_valor);
      dacWrite(dacPin2, DAC2_valor);
      setDigipot(Hdc_min);
    }

    else if (strcmp(cmd, "man") == 0){
      setWavegenFrecuency(f_min);
      setDACsFromHdc(f_max);
      setDigipotFromHac(f_step,Hdc_min);
    }

    else if (strcmp(cmd, "help") == 0){
      Serial.println("");
      Serial.println(">> LISTA DE COMANDOS <<");
      Serial.println("");
      Serial.println("* Para conocer la lista de comandos:");
      Serial.println("    --> help");
      Serial.println("");
      Serial.println("* Solicitar parámetros de calibración:");
      Serial.println("    --> params");
      Serial.println("");
      Serial.println("* Control manual mediante valores crudos de registros:");
      Serial.println("    --> raw f DAC1_valor DAC2_valor digipotValor");
      Serial.println("");
      Serial.println("* Control manual mediante valores de salida deseados:");
      Serial.println("    --> man f Hdc Hac_at_f f_at_Hac");
      Serial.println("");
      Serial.println("* Barrido del campo magnético:");
      Serial.println("    --> sweep f_min f_max f_step Hdc_min Hdc_max Hdc_step Hac_at_f f_at_Hac samples_per_f sample_period");
      Serial.println("");
    }

    else if (strcmp(cmd, "sweep") == 0){
      if (f_min>f_max){Serial.printf("ERROR: La frecuencia mínima no puede ser mayor que la máxima, evidentemente.\n");playMelody(commandError,sizeof(commandError));}
      else if (f_step<f_step_min){Serial.printf("ERROR: Resolución de frecuencia fuera de rango. Valor mínimo permitido: %f Hz\n",f_step_min);playMelody(commandError,sizeof(commandError));}
      //else if (f_step>f_max){Serial.printf("ERROR: La resolución de frecuencia supera la frecuencia máxima.\n");playMelody(commandError,sizeof(commandError));}
      else if (Hdc_min>Hdc_max){Serial.printf("ERROR: El campo H continuo mínimo no puede ser mayor que el máximo, evidentemente.\n");playMelody(commandError,sizeof(commandError));}
      else if (Hdc_max>Hdc_absolute_max){Serial.printf("ERROR: Campo H continuo fuera de rango. Valor máximo permitido: %f Oe\n",Hdc_absolute_max);playMelody(commandError,sizeof(commandError));}
      else if (Hdc_step<Hdc_step_min){Serial.printf("ERROR: Resolución del campo H continuo fuera de rango. Valor mínimo permitido: %f Oe\n",Hdc_step_min);playMelody(commandError,sizeof(commandError));}
      //else if (Hdc_step>Hdc_max){Serial.printf("ERROR: La resolución del campo H continuo supera el campo H continuo máximo\n");playMelody(commandError,sizeof(commandError));}
      else if (samples_per_f<=0){Serial.printf("ERROR: El número de muestras debe ser mayor que cero.\n");playMelody(commandError,sizeof(commandError));}
      else if (sample_period<=0){Serial.printf("ERROR: El periodo de muestreo debe ser mayor que cero.\n");playMelody(commandError,sizeof(commandError));}
      else if (setDigipotFromHac(Hac_at_f,f_at_Hac)){
        float f;
        float Hdc = Hdc_min;
        int valorG;
        int valorP;
        float auxG;
        float auxP;
        float max_valor;
        float max_valor_f;
        barrido = true;
        do {       
          setDACsFromHdc(Hdc);
          delay(5000);       
          f = f_min;
          max_valor=0;
          max_valor_f=0;
          do {
            setWavegenFrecuency(f);
            delay(50);
            auxG=0;
            auxP=0;
            for (int i=0; i<samples_per_f; i++){
              delay(sample_period);
              valorG = analogRead(gainPin);//-900;
              valorP = analogRead(phasePin);
              auxG = auxG+valorG;
              auxP = auxP+valorP;
            }
            auxG = auxG/samples_per_f; //Por alguna extraña razón, no funciona imprimiendo directamente el valor.
            auxP = auxP/samples_per_f;
            if (auxP>max_valor){
              max_valor=auxP;
              max_valor_f=f;
            }
            // if (valor<min_valor){
            //   min_valor=valor;
            //   min_valor_freq=freq;
            // }
            Serial.printf("gpDATA: Hdc: %f Oe    Frecuencia: %f Hz    Ganancia: %f    Fase: %f\n",Hdc,f,auxG, auxP);
            f=f+f_step;
          } while (f<(f_max+f_step) && f_step!=0);
          Serial.printf("HdcDATA: Hdc: %f Oe    fr: %f Hz\n",Hdc,max_valor_f);
          Hdc=Hdc+Hdc_step;
        } while (Hdc<(Hdc_max+Hdc_step) && Hdc_step!=0);
        setDACsFromHdc(0);
        setDigipot(0);
        initializeWavegen();
        barrido = false;
      }
      // request = true;
    }
  }
}

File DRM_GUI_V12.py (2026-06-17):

### *V10: Al tocar el botón de iniciar o al iniciar el barrido en frecuencia para un campo H continuo diferente se borran los datos de la gráfica amplitud/fase.
### *V10: Cuando el microcontrolador reporta un error la etiqueta de notificaciones cambia a color rojo y el texto describe los errores.
import tkinter as tk
from tkinter import font, ttk
import serial
import serial.tools.list_ports
import time
import matplotlib.pyplot as plt
from matplotlib.backends.backend_tkagg import FigureCanvasTkAgg
import re
import csv
from matplotlib.ticker import AutoMinorLocator
from tkinter import filedialog


# --- VARIABLES GLOBALES ---
Hdc_values = []
frecuencia_values = []
amplitud_values = []
fase_values = []
all_frecuencia_values = []
all_amplitud_values = []
all_fase_values = []
Hdc2_values = []
fr_values = []

error_description = ""

# --- PARÁMETROS DE CALIBRACIÓN
f_step_min = 0
Hdc_absolute_max = 0
Hdc_step_min = 0
R = 0
L = 0
k = 0
Vac0 = 0
m = 0

ser = None
linea = ""


# ---------------- FILTRO VID/PID ----------------
VIDS_VALIDOS = [
    0x10C4,  # CP210x (muy común en ESP32)
    0x1A86,  # CH340
    0x0403,  # FTDI
    0x2341   # Arduino
]


def obtener_puertos():
    puertos = serial.tools.list_ports.comports()

    lista = []

    for p in puertos:
        if p.vid in VIDS_VALIDOS:
            lista.append(f"{p.device} - {p.description}")

    return lista


def actualizar_lista_puertos():
    puertos = obtener_puertos()
    combo_puertos["values"] = puertos

    if puertos:
        combo_puertos.current(0)
    else:
        puerto_var.set("Sin puertos compatibles")


def conectar_puerto():
    global ser

    if not puerto_var.get():
        print("No hay puerto seleccionado")
        return

    puerto = puerto_var.get().split(" - ")[0]

    try:
        if ser and ser.is_open:
            ser.close()

        ser = serial.Serial(puerto, 115200, timeout=1)
        time.sleep(2)
        notificar_parametros(f"Conectado a {puerto}")

    except Exception as e:
        ser = None
        notificar_error(f"Error al conectar: {e}")


# ---------------- FUNCIONES SERIAL ----------------

def update_serial_output(comando):
    if ser and ser.is_open:
        ser.write(comando.encode())
        notificar_parametros(f"Comando enviado: {comando}")
        print()
    else:
        notificar_error("Puerto no conectado")

def iniciarBarrido():
    etiqueta_notif.config(text="")
    root.focus_set()

    if not mantener_valores.get():
        del amplitud_values[:]
        del frecuencia_values[:]
        del fase_values[:]
        del all_amplitud_values[:]
        del all_frecuencia_values[:]
        del all_fase_values[:]
        del Hdc2_values[:]
        del fr_values[:]
        actualizar_pgVSf()
        actualizar_frVSHdc()

    f_min = cajetilla_f_min.get().strip()
    if not f_constante.get():
        f_max = cajetilla_f_max.get().strip()
        f_step = cajetilla_f_step.get().strip()
    else:
        f_max = f_min
        f_step = 1
    Hdc_min = cajetilla_Hdc_min.get().strip()
    if not Hdc_constante.get():
        Hdc_max = cajetilla_Hdc_max.get().strip()
        Hdc_step = cajetilla_Hdc_step.get().strip()
    else:
        Hdc_max = Hdc_min
        Hdc_step = 1
    Hac = cajetilla_Hac.get().strip()
    Hac_f = cajetilla_Hac_f.get().strip()
    muestras_f = int(cajetilla_muestras_f.get().strip())
    periodo_mues = int(cajetilla_periodo_mues.get().strip())
    
    comando = f"sweep {f_min} {f_max} {f_step} {Hdc_min} {Hdc_max} {Hdc_step} {Hac} {Hac_f} {muestras_f} {periodo_mues}"
    update_serial_output(comando)

def etiqueta_con_subindice(parent, texto, subtexto, unidades, x, y):
    
    tk.Label(
        parent,
        text=texto,
        font=("Arial", 12,"bold")
    ).place(x=x, y=y)

    tk.Label(
        parent,
        text=subtexto,
        font=("Arial", 7,"bold")
    ).place(x=x+6+len(texto)*12, y=y+12)

    tk.Label(
        parent,
        text="["+unidades+"]:",
        font=("Arial", 12,"bold")
    ).place(x=x+6+12*len(texto)+8*len(subtexto)+10, y=y)

def notificar_error(texto):
    etiqueta_notif.config(text=texto,fg="red")

def notificar_parametros(texto):
    etiqueta_notif.config(text=texto,fg="blue")

def consulta_calib():
    update_serial_output("params")

def actualizar_pgVSf():
    ax1.cla()
    # ax1.scatter(frecuencia_values, amplitud_values, color='blue')
    ax1.plot(frecuencia_values, amplitud_values, '-o', color='blue')
    ax1.set_title("V_mag [mV] VS f [Hz]")
    ax2.cla()
    # ax2.scatter(frecuencia_values, fase_values, color='red')
    ax2.plot(frecuencia_values, fase_values, '-o', color='red')
    ax2.set_title("V_phs [mV] VS f [Hz]")
    ax1.minorticks_on()  # activa subdivisiones
    ax1.grid(which='minor', linestyle=':', linewidth=0.5)  # líneas finas
    ax1.grid(which='major', linestyle=':', linewidth=1)
    ax2.minorticks_on()  # activa subdivisiones
    ax2.grid(which='minor', linestyle=':', linewidth=0.5)  # líneas finas
    ax2.grid(which='major', linestyle=':', linewidth=1)
    canvas1.draw()

def actualizar_frVSHdc():
    ax3.cla()
    # ax3.scatter(frecuencia_values, fase_values, color='green')
    ax3.plot(Hdc2_values, fr_values, '-o', color='green')
    ax3.set_title("f_r [Hz] VS H_DC [Oe]")
    ax3.minorticks_on()  # activa subdivisiones
    ax3.grid(which='minor', linestyle=':', linewidth=0.5)  # líneas finas
    ax3.grid(which='major', linestyle=':', linewidth=1)
    canvas2.draw()

def guardar_pgVSf():   
    ruta = filedialog.asksaveasfilename(
        title="Guardar datos",
        defaultextension=".csv",
        filetypes=[
            ("Archivos CSV", "*.csv"),
            ("Archivos de texto", "*.txt"),
            ("Todos los archivos", "*.*")
        ]
    )

    # El usuario pulsó Cancelar
    if not ruta:
        return

    columnas = [Hdc_values,all_frecuencia_values,all_amplitud_values,all_fase_values]

    try:
        with open(ruta, "w", newline="", encoding="utf-8") as f:
            writer = csv.writer(f)

            # Cabecera opcional
            writer.writerow(["Hdc","Frecuencia", "Amplitud", "Desfase"])

            # Datos
            writer.writerows(zip(*columnas))

        print(f"Datos guardados en: {ruta}")

    except Exception as e:
        print(f"Error al guardar: {e}")
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

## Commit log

2026-06-28 Modelos 3D del sistema de solenoides.
    [Soporte bobina V5.scad, baseLeft_V5.stl, baseRight_V5.stl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]
2026-07-06 Imágenes del diseño del circuito impreso (PCB)
2026-07-06 Diagramas de flujo
2026-07-06 Archivos del proyecto de KiCad
    [Detector de resonancia magnetoelástica V1.kicad_pcb, Detector de resonancia magnetoelástica V1.kicad_sch]
2026-07-16 Modelos 3D
    [Soporte bobina V5.scad, baseLeft_V5.stl, baseRight_V5.stl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]
